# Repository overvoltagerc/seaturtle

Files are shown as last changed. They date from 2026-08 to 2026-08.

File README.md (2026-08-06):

<p align="center">
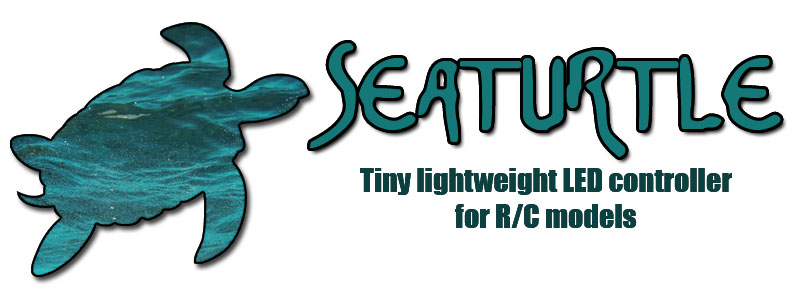
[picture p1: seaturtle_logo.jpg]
SEATURTLE Logo
  
</p>

<p align="center">
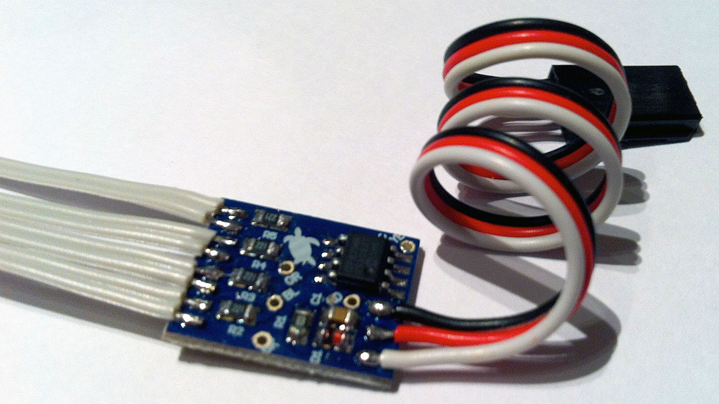
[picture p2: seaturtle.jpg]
SEATURTLE - la scheda
  
</p>

# SEATURTLE — Tiny lightweight LED controller for R/C models

SEATURTLE è una centralina luci pensata per essere il più piccola e leggera possibile: monta tutti i componenti in SMD su un PCB di pochi millimetri, con un solo connettore di ingresso dalla ricevente e quattro uscite per i LED del modello.

Questo repository contiene **quattro firmware alternativi**, per due tipologie di modello (drift / switch) in due varianti ciascuno (classic / xenon):

| Firmware | Cartella | Uscite | Note |
|---|---|---|---|
| **Drift Classic** | [`/fw/2016_drift_classic`](fw/2016_drift_classic) | fari, coda, retro, scarico | fari anteriori bianco caldo |
| **Drift Xenon** | [`/fw/2016_drift_xenon`](fw/2016_drift_xenon) | fari, coda, retro, scarico | fari anteriori con effetto xenon (bianco freddo, accensione graduale) |
| **Switch Classic** | [`/fw/2016_switch_classic`](fw/2016_switch_classic) | fari (x2), coda (x2) | semplice ON/OFF in base al canale radio |
| **Switch Xenon** | [`/fw/2016_switch_xenon`](fw/2016_switch_xenon) | fari (x2), coda (x2) | come Switch Classic, con effetto xenon in accensione sui fari |

Non è disponibile un manuale ufficiale per nessuna delle quattro versioni: il funzionamento — comprese le procedure di calibrazione/programmazione — è descritto qui sotto.

## 1. Il progetto

SEATURTLE ha un solo connettore di ingresso dalla ricevente e 4 uscite a due poli per il collegamento diretto dei LED. L'alimentazione richiesta è compresa tra 4,5V e 6,5V, prelevata direttamente dal modello.

Nelle versioni **Drift**, tramite uno sdoppiatore per cavi servo, la centralina va collegata in parallelo al regolatore motore, in modo che il segnale di gas/freno arrivi sia all'ESC sia alla SEATURTLE. Nelle versioni **Switch**, l'ingresso va invece collegato a un canale libero della ricevente (tipicamente un canale ausiliario a 2 posizioni) usato semplicemente come interruttore per le luci.

## 2. Funzionamento del firmware

### Drift Classic / Drift Xenon

Il firmware (`SeaTurtle.c`) legge il canale gas/freno dell'ESC e gestisce quattro uscite: fari anteriori (`HEAD`), luci posteriori (`TAIL`), retromarcia (`REV`) ed effetto fiammata di scarico (`EXH`, con un pattern di lampeggio "backfire" predefinito).

**Calibrazione (`userSetup()`)**: all'accensione, dopo la sincronizzazione sul segnale PPM, il firmware controlla se il canale gas è tenuto fuori dalla zona centrale (sotto 1400µs o sopra 1600µs, cioè a fondo corsa in una direzione qualsiasi). In quel caso entra in modalità programmazione:

1. Tutte le uscite si accendono (`ALL_ON()`) a indicare che la centralina è in fase di apprendimento.
2. In base al lato verso cui il gas è tenuto premuto (avanti o indietro rispetto al centro), il firmware deduce se il canale è **invertito** (`PPM_reverse`) e insegue il valore di fondo scala finché il segnale continua ad allontanarsi dal centro.
3. Al rilascio del gas (ritorno in zona centrale), il firmware salva in EEPROM il valore di fondo scala (`EEPROM_PPMFULL`) e, dopo una nuova sincronizzazione, il valore di neutro (`EEPROM_PPMNEUTRAL`), marcando la scheda come collaudata (`EEPROM_TESTED`).
4. Da quel momento, a ogni accensione successiva, la centralina carica questi valori dall'EEPROM e li usa per determinare in tempo reale marcia avanti/frenata/retromarcia — senza bisogno di ripetere la calibrazione, a meno che non la si rifaccia volontariamente ripetendo la stessa procedura.

**Scheda "vergine" (`hardwareTest()`)**: se la scheda non è ancora mai stata calibrata (EEPROM di fabbrica, non ancora scritta), invece di funzionare normalmente il firmware entra in un semplice loop di test hardware, che accende una singola uscita alla volta in base alla posizione istantanea del canale letto (una soglia diversa per ciascuna delle 4 uscite HEAD/TAIL/REV/EXH), utile in produzione per verificare rapidamente che scheda e collegamenti funzionino, senza dover prima eseguire la calibrazione.

L'unica differenza tra le due varianti è l'effetto dei fari anteriori: **Classic** li accende semplicemente a piena luminosità (bianco caldo), mentre **Xenon** li accende con un effetto di accensione graduale a PWM (tipico delle lampade allo xeno, reso con luci bianco freddo).

### Switch Classic / Switch Xenon

Il firmware (`SeaTurtle.c`, versione switch) è molto più semplice: legge un singolo canale a 2 posizioni e si limita ad accendere (`HEAD1/HEAD2`, `TAIL1/TAIL2`) o spegnere tutti i LED in base alla posizione del canale, con una soglia fissa a 1500µs e una piccola isteresi anti-glitch. **Non usa l'EEPROM e non richiede alcuna calibrazione**: basta collegarla e usarla.

Anche qui l'unica differenza tra le due varianti è l'effetto dei fari: **Classic** li accende/spegne di netto, **Xenon** aggiunge lo stesso effetto di accensione graduale a PWM della versione Drift Xenon, applicato ai fari anteriori.

## 3. Compilatore

Tutti e quattro i firmware sono scritti per **mikroC PRO for PIC** di [MikroElektronika](https://www.mikroe.com/mikroc-pic), per lo stesso microcontrollore **PIC12F629** usato in Grizzly3 (datasheet in [`/ref`](ref/PIC12F629-675.pdf)), e rientrano tutti ampiamente nel limite di 2048 program word della licenza gratuita:

| Firmware | ROM usata | % sul totale |
|---|---|---|
| Drift Classic | 605 / 1024 word | 59% |
| Drift Xenon | 662 / 1024 word | 65% |
| Switch Classic | 159 / 1024 word | 16% |
| Switch Xenon | 222 / 1024 word | 22% |

Non è quindi necessaria alcuna licenza a pagamento per compilare o modificare questi firmware.

## 4. Programmazione della scheda

**Non è necessario mettere mano al codice sorgente.** Per programmare la scheda è sufficiente collegare il PIC12F629 a un programmatore compatibile, ad esempio un **PICkit 2/3/4**, e caricare il file `.hex` già compilato della versione desiderata (nella rispettiva cartella `/fw/2016_*`).

Il PCB espone 5 pad ICSP (`VPP`, `VDD`, `GND`, `PGD`, `PGC`), con la disposizione mostrata nello schema seguente:

<p align="center">
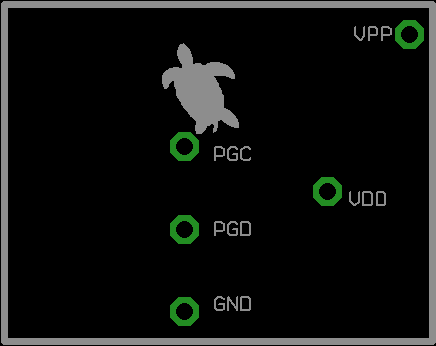
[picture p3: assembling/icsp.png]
Piedinatura ICSP SEATURTLE
  
</p>

Non sono richieste altre operazioni dopo il flashing, ma va tenuto presente il comportamento del firmware al primo avvio:
- nelle versioni **Drift**, appena flashata la scheda non è ancora calibrata: finché non si esegue almeno una volta la procedura di programmazione (tenere il gas a fondo, in avanti o indietro, all'accensione, e poi rilasciarlo — vedi punto 2), il firmware resta in un loop di test che si limita ad accendere un'uscita alla volta in base alla posizione del canale, utile per un rapido collaudo ma non rappresentativo del funzionamento normale;
- nelle versioni **Switch** non è prevista alcuna calibrazione: la scheda è già pronta all'uso non appena flashata.

## 5. Il PCB

Il circuito stampato è stato disegnato in **Eagle CAD** (file sorgente: [`/brd/seaturtle.brd`](brd/seaturtle.brd)).

Nella cartella [`/brd/gerber`](brd/gerber) sono presenti tutti i file Gerber (e uno `.zip` già pronto con l'intero pacchetto, `gerber_seaturtle.zip`) necessari per far produrre il PCB su un servizio di fabbricazione esterno, ad esempio [JLCPCB](https://jlcpcb.com/), [PCBWay](https://www.pcbway.com/) o simili: è sufficiente caricare l'archivio `.zip` (o i singoli file Gerber) nel loro configuratore online per ottenere un preventivo e ordinare le schede.

Nella cartella [`/assembling`](assembling) è presente la distinta componenti (`componenti.xls`), utile per l'assemblaggio della scheda (tutti componenti SMD in package 0805, PIC12F629-I/SN).

## Struttura del repository

```
seaturtle/
├── assembling/      # Distinta componenti e schema piedinatura ICSP
├── brd/             # Progetto Eagle CAD (.brd) e file Gerber
├── fw/
│   ├── 2016_drift_classic/    # Fari bianco caldo, calibrazione automatica
│   ├── 2016_drift_xenon/      # Come sopra, con effetto xenon sui fari
│   ├── 2016_switch_classic/   # Semplice ON/OFF via canale radio
│   └── 2016_switch_xenon/     # Come sopra, con effetto xenon sui fari
├── ref/             # Datasheet PIC12F629/675
├── seaturtle.jpg
└── seaturtle_logo.jpg
```

## Licenza

Questo progetto è distribuito con licenza **MIT** — vedi il file [LICENSE](LICENSE).

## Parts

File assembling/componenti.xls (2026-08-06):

SIMBOLO | COMPONENTE | COD. FARNELL | Q.TA' | NOTE
R1 | Res 1k 0805 | 2073606 | 1
R2-R5 | Res 220 0805 | 2074404 | 4
C1 | Cond 100nF 16V 0805 | 1759143 | 1
D1 | Diodo SMD | 9550089 | 1
PIC | PIC 12F629-I/SN | 9759000 | 1

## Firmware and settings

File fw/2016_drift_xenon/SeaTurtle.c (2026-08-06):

/* SEATURTLE
    2016 tHeo
    Firmware 1.0
    
Changelog:

27/03/16 > Porting dal firmware RCDriftLightUnit
    
*/

#include "SeaTurtle.h"

// CONFIGURAZIONE PIN
// Utilizzo i TRIS per passare da "acceso" a "floating" in modo da evitare danni in caso di cortocircuiti

sbit PPM at GP5_bit; // Segnale PPM in ingresso da ricevente
sbit EXH at TRISIO4_bit;
sbit REV at TRISIO2_bit;
sbit TAIL at TRISIO1_bit;
sbit HEAD at TRISIO0_bit;

// VARIABILI

unsigned char PPM_level = 0;
unsigned char PPM_start = 0;
unsigned char PPM_value = PPM_1500_US;
unsigned char PPM_updated = 0;

unsigned char PPM_neutral = 0;
unsigned char PPM_full = PPM_1500_US;
unsigned char PPM_antiglitch = 0;
unsigned char PPM_reverse = 0;
unsigned char PPM_maxzero;
unsigned char PPM_minzero;
unsigned char PPM_command = CMD_IDLE;

unsigned char new_user_cmd = 0;

unsigned int XENON_delay = 0;

unsigned char REV_status = 0;

unsigned char EXH_threshold;
unsigned char EXH_heat = 0;
unsigned char EXH_sequence = 0;
unsigned char EXH_delay = 0;
unsigned char EXH_bit = 0;

unsigned char PWM_i = 0;
unsigned char HEAD_pwm = PWM_OFF;
unsigned char TAIL_pwm = PWM_OFF;

unsigned char i;

void interrupt()
{
    if(GPIF_bit)
    {
        if(PPM && !PPM_level)
        {
            PPM_start = TMR0;
            PPM_level = 1;
        }
        else if(!PPM && PPM_level)
        {
            PPM_value = TMR0 - PPM_start;
            PPM_level = 0;
            PPM_updated = 1;
        }

        GPIF_bit = 0;
    }
}

void syncPPM(unsigned char frames)
{
    // Attendo segnale PPM valido
    i = 0;
    while(i < frames)
    {
        PPM_updated = 0;
        while(!PPM_updated);
        if(PPM_value > PPM_MIN_VALID)
            i++;
        else
            i = 0;
    }
}

void hardwareTest()
{
    while(1)
    {
        PPM_updated = 0;
        while(!PPM_updated);
        
        if(PPM_value < PPM_1250_US)
        {
            HEAD = 0;
            TAIL = 1;
            REV = 1;
            EXH = 1;
        }
        else if(PPM_value < PPM_1500_US)
        {
            HEAD = 1;
            TAIL = 0;
            REV = 1;
            EXH = 1;
        }
        else if(PPM_value < PPM_1750_US)
        {
            HEAD = 1;
            TAIL = 1;
            REV = 0;
            EXH = 1;
        }
        else
        {
            HEAD = 1;
            TAIL = 1;
            REV = 1;
            EXH = 0;
        }
    }
}

void userSetup()
{
    // PROGRAMMAZIONE UTENTE
    ALL_ON();

    // Leggo il segnale massimo
    i = 0;
    if(PPM_value > PPM_1500_US)
    {
        PPM_reverse = 0;
        while(i < PROGRAM_PPM_FRAMES)
        {
            PPM_updated = 0;
            while(!PPM_updated);

            if(PPM_value > PPM_full)
            {
               PPM_full = PPM_value;
               i = 0;
            }
            else
                i++;
        }
    }
    else
    {
        PPM_reverse = 1;
        while(i < PROGRAM_PPM_FRAMES)
        {
            PPM_updated = 0;
            while(!PPM_updated);

            if(PPM_value < PPM_full)
            {
               PPM_full = PPM_value;
               i = 0;
            }
            else
                i++;
        }
    }

    // Salvo valore gas massimo
    EEPROM_Write(EEPROM_PPMFULL, PPM_full);
    
    ALL_OFF();
    
    // Aspetto che l'utente lasci il comando
    while(PPM_value > PPM_1600_US || PPM_value < PPM_1400_US);
    
    // Salvo valore gas neutro
    syncPPM(PROGRAM_PPM_FRAMES);
    PPM_neutral = PPM_value;
    EEPROM_Write(EEPROM_PPMNEUTRAL, PPM_neutral);
    EEPROM_Write(EEPROM_TESTED, 0);
}

void main() {
    // INIZIALIZZAZIONE HARDWARE

    asm {
        bsf STATUS, RP0
        call 0x03ff
        movwf OSCCAL
        bcf STATUS, RP0
    }                           // Calibrazione oscillatore interno

    CMCON = 0b00010111;         // Comparatori OFF
    OPTION_REG = 0b00000010;    // TMR0 con prescaler 1/8 (ciclo 2,048 msec), pull-up abilitati

    GIE_bit = 1;                // Interrupt generale abilitato
    GPIE_bit = 1;               // Interrupt-On-Change abilitato
    IOC = 0b00100000;           // IOC abilitato su GP5 (PPM)
    WPU = 0b00100000;           // Weak pull-up abilitato solo su GP5 (PPM)

    TRISIO5_bit = 1;

    ALL_OFF();
    GPIO = 0xFF;        // Tutti i buffer di uscita accesi

    // Attendo segnale
    syncPPM(STARTUP_PPM_FRAMES);
    
    // Se sto accelerando, entro in programmazione
    if(PPM_value < PPM_1400_US || PPM_value > PPM_1600_US)
        userSetup();
        
    Delay_ms(500);

    // Prima accensione
    if(EEPROM_Read(EEPROM_TESTED) == 0xFF)
        hardwareTest();
    
    // Carico programmazione
    PPM_neutral = EEPROM_Read(EEPROM_PPMNEUTRAL);
    PPM_minzero = PPM_neutral - NEUTRAL_RANGE;
    PPM_maxzero = PPM_neutral + NEUTRAL_RANGE;
    PPM_full = EEPROM_Read(EEPROM_PPMFULL);
    if(PPM_full < PPM_neutral)
    {
        PPM_reverse = 1;
        EXH_threshold = PPM_neutral - ((PPM_neutral - PPM_full) / 2);
    }
    else
        EXH_threshold = PPM_neutral + ((PPM_full - PPM_neutral) / 2);

    // Inizializzazione comando
    PPM_command = CMD_IDLE;
    
    // Accendo le luci di coda
    TAIL_pwm = PWM_DIM;
        
    // Accendo fari xenon
    HEAD = 0;  // Primo flash
    Delay_ms(10);
    while(HEAD_pwm < PWM_FULL)
    {
        Delay_us(PWM_DELAY_US);
        
        if(++XENON_delay == XENON_HEAT)
        {
            XENON_delay = 0;
            HEAD_pwm++;
        }

        if(++PWM_i > PWM_CYCLE)
            PWM_i = 0;
        if(HEAD_pwm > PWM_i) HEAD = 0; else HEAD = 1;
        if(TAIL_pwm > PWM_i) TAIL = 0; else TAIL = 1;
    }
        
    // Loop principale!
     while(1)
     {
         if(PPM_updated)
         {
             // Verifica la posizione del canale
             if(PPM_value > PPM_maxzero)
             {
                 if(PPM_antiglitch < ANTIGLITCH_ZERO + ANTIGLITCH_COUNT)
                 {
                     PPM_antiglitch++;
                     PPM_command = CMD_IDLE;
                 }
                 else
                 {
                     if(PPM_reverse)
                         PPM_command = CMD_BRAKE;
                     else
                         PPM_command = CMD_FORWARD;
                 }
             }
             else if(PPM_value < PPM_minzero)
             {
                 if(PPM_antiglitch > ANTIGLITCH_ZERO - ANTIGLITCH_COUNT)
                 {
                     PPM_antiglitch--;
                     PPM_command = CMD_IDLE;
                 }
                 else
                 {
                     if(PPM_reverse)
                         PPM_command = CMD_FORWARD;
                     else
                         PPM_command = CMD_BRAKE;
                 }
             }
             else
             {
                 PPM_antiglitch = ANTIGLITCH_ZERO;
                 PPM_command = CMD_IDLE;
             }

             // Gestisco le uscite in base alla posizione del canale
             switch(PPM_command)
             {
                 case CMD_FORWARD:
                     // Spengo luci di stop
                     TAIL_pwm = PWM_DIM;
                     // Disattivo la retromarcia
                     REV = 1;
                     REV_status = REV_OFF;
                     // Temperatura di scarico
                     if(PPM_reverse)
                     {
                         if(PPM_value < EXH_threshold && EXH_heat < EXH_MAX_TEMP)
                             EXH_heat++;
                         else if(EXH_heat)
                             EXH_heat--;
                     }
                     else
                     {
                       if(PPM_value > EXH_threshold && EXH_heat < EXH_MAX_TEMP)
                           EXH_heat++;
                       else if(EXH_heat)
                           EXH_heat--;
                     }
                     break;

                 case CMD_BRAKE:
                     // Se ho già frenato, accendo le luci di retromarcia
                     if(REV_status == REV_ACTIVE)
                         REV = 0;
                     // Altrimenti accendo gli stop e attivo la retro per la prossima frenata
                     else
                     {
                         TAIL_pwm = PWM_FULL;
                         REV_status = REV_BRAKE;
                     }
                     // Gestione fiammata
                     if(EXH_heat >= EXH_IGNITION_TEMP)
                     {
                         // Attivazione sequenza fiammata
                         EXH_sequence = backfire[TMR0 & 0b00000011];
                         EXH_bit = 7;
                         EXH_heat = 0;
                     }
                     else if(EXH_heat)
                         EXH_heat--;
                     break;

                 default:
                     // Spengo luci di stop
                     TAIL_pwm = PWM_DIM;
                     // Preparo la retro in caso si freni ancora
                     if(REV_status == REV_BRAKE)
                         REV_status = REV_ACTIVE;
                     // Gestione fiammata
                     if(EXH_heat >= EXH_IGNITION_TEMP)
                     {
                         // Attivazione sequenza fiammata
                         EXH_sequence = backfire[TMR0 & 0b00000011];
                         EXH_bit = 7;
                         EXH_heat = 0;
                     }
                     else if(EXH_heat)
                         EXH_heat--;
             }

              PPM_updated = 0;
         }

        // Fiammata
        if(--EXH_delay == 0)
        {
            EXH_delay = EXH_DELAY_CYCLES;
             if(EXH_bit)
            {
                EXH_bit--;
                EXH = !EXH_sequence.B0;
                EXH_sequence = EXH_sequence >> 1;
            }
        }
             
        if(++PWM_i > PWM_CYCLE)
            PWM_i = 0;
        if(TAIL_pwm > PWM_i) TAIL = 0; else TAIL = 1;

        Delay_us(PWM_DELAY_US);
     }
}

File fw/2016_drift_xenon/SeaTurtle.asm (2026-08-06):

_interrupt:
	MOVWF      R15+0
	SWAPF      STATUS+0, 0
	CLRF       STATUS+0
	MOVWF      ___saveSTATUS+0
	MOVF       PCLATH+0, 0
	MOVWF      ___savePCLATH+0
	CLRF       PCLATH+0

;SeaTurtle.c,55 :: 		void interrupt()
;SeaTurtle.c,57 :: 		if(GPIF_bit)
	BTFSS      GPIF_bit+0, BitPos(GPIF_bit+0)
	GOTO       L_interrupt0
;SeaTurtle.c,59 :: 		if(PPM && !PPM_level)
	BTFSS      GP5_bit+0, BitPos(GP5_bit+0)
	GOTO       L_interrupt3
	MOVF       _PPM_level+0, 0
	BTFSS      STATUS+0, 2
	GOTO       L_interrupt3
L__interrupt107:
;SeaTurtle.c,61 :: 		PPM_start = TMR0;
	MOVF       TMR0+0, 0
	MOVWF      _PPM_start+0
;SeaTurtle.c,62 :: 		PPM_level = 1;
	MOVLW      1
	MOVWF      _PPM_level+0
;SeaTurtle.c,63 :: 		}
	GOTO       L_interrupt4
L_interrupt3:
;SeaTurtle.c,64 :: 		else if(!PPM && PPM_level)
	BTFSC      GP5_bit+0, BitPos(GP5_bit+0)
	GOTO       L_interrupt7
	MOVF       _PPM_level+0, 0
	BTFSC      STATUS+0, 2
	GOTO       L_interrupt7
L__interrupt106:
;SeaTurtle.c,66 :: 		PPM_value = TMR0 - PPM_start;
	MOVF       _PPM_start+0, 0
	SUBWF      TMR0+0, 0
	MOVWF      _PPM_value+0
;SeaTurtle.c,67 :: 		PPM_level = 0;
	CLRF       _PPM_level+0
;SeaTurtle.c,68 :: 		PPM_updated = 1;
	MOVLW      1
	MOVWF      _PPM_updated+0
;SeaTurtle.c,69 :: 		}
L_interrupt7:
L_interrupt4:
;SeaTurtle.c,71 :: 		GPIF_bit = 0;
	BCF        GPIF_bit+0, BitPos(GPIF_bit+0)
;SeaTurtle.c,72 :: 		}
L_interrupt0:
;SeaTurtle.c,73 :: 		}
L_end_interrupt:
L__interrupt113:
	MOVF       ___savePCLATH+0, 0
	MOVWF      PCLATH+0
	SWAPF      ___saveSTATUS+0, 0
	MOVWF      STATUS+0
	SWAPF      R15+0, 1
	SWAPF      R15+0, 0
	RETFIE
; end of _interrupt

_syncPPM:

;SeaTurtle.c,75 :: 		void syncPPM(unsigned char frames)
;SeaTurtle.c,78 :: 		i = 0;
	CLRF       _i+0
;SeaTurtle.c,79 :: 		while(i < frames)
L_syncPPM8:
	MOVF       FARG_syncPPM_frames+0, 0
	SUBWF      _i+0, 0
	BTFSC      STATUS+0, 0
	GOTO       L_syncPPM9
;SeaTurtle.c,81 :: 		PPM_updated = 0;
	CLRF       _PPM_updated+0
;SeaTurtle.c,82 :: 		while(!PPM_updated);
L_syncPPM10:
	MOVF       _PPM_updated+0, 0
	BTFSS      STATUS+0, 2
	GOTO       L_syncPPM11
	GOTO       L_syncPPM10
L_syncPPM11:
;SeaTurtle.c,83 :: 		if(PPM_value > PPM_MIN_VALID)
	MOVF       _PPM_value+0, 0
	SUBLW      112
	BTFSC      STATUS+0, 0
	GOTO       L_syncPPM12
;SeaTurtle.c,84 :: 		i++;
	INCF       _i+0, 1
	GOTO       L_syncPPM13
L_syncPPM12:
;SeaTurtle.c,86 :: 		i = 0;
	CLRF       _i+0
L_syncPPM13:
;SeaTurtle.c,87 :: 		}
	GOTO       L_syncPPM8
L_syncPPM9:
;SeaTurtle.c,88 :: 		}
L_end_syncPPM:
	RETURN
; end of _syncPPM

_hardwareTest:

;SeaTurtle.c,90 :: 		void hardwareTest()
;SeaTurtle.c,92 :: 		while(1)
L_hardwareTest14:
;SeaTurtle.c,94 :: 		PPM_updated = 0;
	CLRF       _PPM_updated+0
;SeaTurtle.c,95 :: 		while(!PPM_updated);
L_hardwareTest16:
	MOVF       _PPM_updated+0, 0
	BTFSS      STATUS+0, 2
	GOTO       L_hardwareTest17
	GOTO       L_hardwareTest16
L_hardwareTest17:
;SeaTurtle.c,97 :: 		if(PPM_value < PPM_1250_US)
	MOVLW      156
	SUBWF      _PPM_value+0, 0
	BTFSC      STATUS+0, 0
	GOTO       L_hardwareTest18
;SeaTurtle.c,99 :: 		HEAD = 0;
	BCF        TRISIO0_bit+0, BitPos(TRISIO0_bit+0)
;SeaTurtle.c,100 :: 		TAIL = 1;
	BSF        TRISIO1_bit+0, BitPos(TRISIO1_bit+0)
;SeaTurtle.c,101 :: 		REV = 1;
	BSF        TRISIO2_bit+0, BitPos(TRISIO2_bit+0)
;SeaTurtle.c,102 :: 		EXH = 1;
	BSF        TRISIO4_bit+0, BitPos(TRISIO4_bit+0)
;SeaTurtle.c,103 :: 		}
	GOTO       L_hardwareTest19
L_hardwareTest18:
;SeaTurtle.c,104 :: 		else if(PPM_value < PPM_1500_US)
	MOVLW      188
	SUBWF      _PPM_value+0, 0
	BTFSC      STATUS+0, 0
	GOTO       L_hardwareTest20
;SeaTurtle.c,106 :: 		HEAD = 1;
	BSF        TRISIO0_bit+0, BitPos(TRISIO0_bit+0)
;SeaTurtle.c,107 :: 		TAIL = 0;
	BCF        TRISIO1_bit+0, BitPos(TRISIO1_bit+0)
;SeaTurtle.c,108 :: 		REV = 1;
	BSF        TRISIO2_bit+0, BitPos(TRISIO2_bit+0)
;SeaTurtle.c,109 :: 		EXH = 1;
	BSF        TRISIO4_bit+0, BitPos(TRISIO4_bit+0)
;SeaTurtle.c,110 :: 		}
	GOTO       L_hardwareTest21
L_hardwareTest20:
;SeaTurtle.c,111 :: 		else if(PPM_value < PPM_1750_US)
	MOVLW      219
	SUBWF      _PPM_value+0, 0
	BTFSC      STATUS+0, 0
	GOTO       L_hardwareTest22
;SeaTurtle.c,113 :: 		HEAD = 1;
	BSF        TRISIO0_bit+0, BitPos(TRISIO0_bit+0)
;SeaTurtle.c,114 :: 		TAIL = 1;
	BSF        TRISIO1_bit+0, BitPos(TRISIO1_bit+0)
;SeaTurtle.c,115 :: 		REV = 0;
	BCF        TRISIO2_bit+0, BitPos(TRISIO2_bit+0)
;SeaTurtle.c,116 :: 		EXH = 1;
	BSF        TRISIO4_bit+0, BitPos(TRISIO4_bit+0)
;SeaTurtle.c,117 :: 		}
	GOTO       L_hardwareTest23
L_hardwareTest22:
;SeaTurtle.c,120 :: 		HEAD = 1;
	BSF        TRISIO0_bit+0, BitPos(TRISIO0_bit+0)
;SeaTurtle.c,121 :: 		TAIL = 1;
	BSF        TRISIO1_bit+0, BitPos(TRISIO1_bit+0)
;SeaTurtle.c,122 :: 		REV = 1;
	BSF        TRISIO2_bit+0, BitPos(TRISIO2_bit+0)
;SeaTurtle.c,123 :: 		EXH = 0;
	BCF        TRISIO4_bit+0, BitPos(TRISIO4_bit+0)
;SeaTurtle.c,124 :: 		}
L_hardwareTest23:
L_hardwareTest21:
L_hardwareTest19:
;SeaTurtle.c,125 :: 		}
	GOTO       L_hardwareTest14
;SeaTurtle.c,126 :: 		}
L_end_hardwareTest:
	RETURN
; end of _hardwareTest

_userSetup:
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
